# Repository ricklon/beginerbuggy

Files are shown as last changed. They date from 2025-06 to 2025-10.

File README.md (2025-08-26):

# Beginner Buggy
*A 1-pound combat robot platform for getting started in robot combat sports*





## 🤖 Project Overview

The **Beginner Combat Buggy** is an educational 1-pound antweight combat robot platform, designed to be fully 3D printed in plastic and compliant with antweight competition rules. This project provides a complete, buildable design that teaches fundamental robotics concepts while preparing participants for competition.

### Key Features
- **Competition Ready:** Meets standard 1lb plastic antweight combat robot specifications
- **Educational Focus:** Step-by-step learning experience for all skill levels
- **Modular Design:** Easy to modify, repair, and upgrade
- **Community Driven:** Open-source design with active builder support

### What You'll Learn
- Combat robot design principles
- Electronics integration and safety systems
- Mechanical assembly and fastening techniques
- Battery management and power systems
- Radio control and failsafe programming
- Competition preparation and strategy

## 📋 Specifications

| Specification | Value |
|---|---|
| **Weight Class** | 1 pound (454g) maximum |
| **Drive System** | Differential drive, tank steering |
| **Power System** | 2-4S LiPo battery with kill switch |
| **Control** | 2.4GHz radio with failsafe |
| **Motors** | Brushed gear motors |
| **ESC Options** | Repeat Robotics Budget Dual ESC<br>Weka 20A v2.2 Dual ESC |
| **Weapon Class** | Beginner-friendly (spinner/wedge/lifter) |
| **Arena Size** | Standard combat robotics arenas |

## 🚀 Getting Started

### Prerequisites
- Basic electronics knowledge (helpful but not required)
- Access to soldering equipment
- Precision scale (0.1g accuracy)
- Standard hobby tools

### Quick Start
1. **Read the Documentation** - Start with this README and the assembly guide
2. **Join the Community** - Connect with FUBAR Labs for build sessions
3. **Gather Materials** - Use the provided parts list and suppliers
4. **Attend Build Night** - Join a guided build session (recommended for beginners)
5. **Build and Test** - Follow the step-by-step assembly guide
6. **Compete** - Enter local antweight competitions

### Build Options
- **Guided Build Session** - Join FUBAR Labs build nights for hands-on instruction
- **Solo Build** - Follow the detailed assembly guide independently
- **Workshop Build** - Organize a group build at your local makerspace

## 📚 Documentation

### Core Documentation
- **[Assembly Guide](ASSEMBLY.md)** - Complete step-by-step build instructions
- **[Parts List](PARTS.md)** - Detailed component specifications and suppliers
- **[Competition Guide](COMPETITION.md)** - Rules, strategy, and event preparation

### Technical Resources
- **[Wiring Diagrams](docs/wiring/)** - Electrical schematics and connection guides
- **[CAD Files](cad/)** - 3D models and mechanical drawings
- **[Programming Guide](docs/programming/)** - ESC setup and radio configuration
- **[Troubleshooting](docs/troubleshooting/)** - Common issues and solutions

## 🔧 Hardware Components

### Electronics Package
- **Motor Controllers:** Repeat Robotics Budget Dual ESC or Weka 20A v2.2
- **Microcontroller:** Xiao development board
- **Power:** 2-4S LiPo battery with XT30 connectors
- **Safety:** Kill switch and weapon safety lock
- **Control:** 2.4GHz radio system with failsafe

### Mechanical Components
- **Chassis:** Lightweight aluminum or titanium frame
- **Drive:** Brushed gear motors with wheels
- **Fasteners:** High-strength bolts and grub screws
- **Protection:** Impact-resistant component mounting

### Tool Requirements
- Hex keys (2mm, 2.5mm, 4mm, 1.5mm)
- Torx keys (TBD)
- 7/16" wrench for lock nuts
- Soldering iron and supplies
- Precision scale (0.1g accuracy)
- Safety equipment (glasses, gloves)

## ⚡ Safety First

**🚨 IMPORTANT SAFETY NOTICE 🚨**

Combat robots involve weapons, high-energy systems, and LiPo batteries. **Safety is not optional.**

### Critical Safety Features
- **Kill Switch:** Emergency power disconnection
- **Weapon Safety Lock:** Physical weapon power removal
- **Block Testing:** Always elevate robot during testing
- **Battery Safety:** Proper LiPo handling and charging
- **Arena Requirements:** Contained testing environment

### Before You Build
- Read all safety documentation thoroughly
- Understand local regulations and venue requirements
- Have appropriate safety equipment available
- Know emergency procedures for electrical and fire hazards

**Never operate a combat robot without proper safety measures in place.**

## 🏆 Competition Information

### Competition Classes
- **Primary:** 1-pound plastic antweight class
- **Progression:** Path to 3lb, 12lb, and higher weight classes
- **Rules:** SPARC (Safety and Performance in Robotic Competition) guidelines

### Local Events
- **FUBAR Labs "Mechanical Mayhem"** - Regular antweight competitions
- **Regional Events** - Connect with broader combat robotics community
- **Tournament Formats** - Single elimination, round robin, skill challenges

### Getting Competition Ready
1. **Technical Inspection** - Pass safety and rules compliance check
2. **Weight Verification** - Confirm 1.000 lb maximum weight
3. **Safety Demonstration** - Prove all safety systems function
4. **Driver Preparation** - Practice maneuvering and weapon control

## 🛠️ Build Support

### FUBAR Labs Build Nights
- **Location:** FUBAR Labs makerspace
- **Schedule:** [Check calendar for dates]
- **What's Provided:** Tools, workspace, expert guidance
- **What to Bring:** Components, enthusiasm

### Community Support
- **Discord/Slack:** Real-time chat with builders and competitors
- **Build Photos:** Share progress and get feedback
- **Technical Help:** Troubleshooting assistance from experienced builders
- **Competition Prep:** Strategy and setup guidance

### Mentorship Program
- Pair new builders with experienced combat roboticists
- One-on-one guidance through first build and competition
- Ongoing support for design improvements and upgrades

## 📈 Project Roadmap

### Version 1.0 (Current)
- [x] Complete mechanical design
- [x] Electronics integration guide
- [x] Safety protocols established
- [x] Assembly documentation
- [ ] Competition validation
- [ ] Community feedback integration

### Version 2.0 (Planned)
- [ ] Advanced weapon options
- [ ] Weight optimization improvements
- [ ] CAD file refinements
- [ ] Video build tutorials
- [ ] Multi-language documentation

## 🤝 Contributing

We welcome contributions from builders, competitors, and educators!

### How to Contribute
- **Documentation:** Improve guides, add translations, create tutorials
- **Design:** Mechanical improvements, weight optimization, new features
- **Testing:** Build validation, competition feedback, safety verification
- **Community:** Organize build events, mentor new builders, share experiences

### Contribution Guidelines
1. Fork the repository
2. Create a feature branch
3. Make your changes with clear documentation
4. Test thoroughly (especially safety-related changes)
5. Submit a pull request with detailed description

### Code of Conduct
- **Safety First:** All contributions must prioritize builder and spectator safety
- **Inclusive Community:** Welcome builders of all skill levels and backgrounds
- **Open Collaboration:** Share knowledge freely and support others' learning
- **Responsible Innovation:** Consider the impact of changes on the community

## 📄 License and Legal

### Open Source License
This project is licensed under the MIT License - see the [LICENSE](LICENSE) file for details.

### Safety Disclaimer
**IMPORTANT:** Combat robotics involves inherent risks. Builders and operators assume full responsibility for safety. This project provides guidelines but cannot guarantee safety - always prioritize proper safety measures and follow local regulations.

### Competition Compliance
While designed to meet standard competition rules, builders are responsible for verifying compliance with specific event regulations. Rules may vary by competition and region.

## 🔗 Resources and Links

### Essential Reading
- [SPARC Safety Guidelines](https://sparc.tools/)
- [Combat Robotics Design Guidelines](https://www.robotcombat.com/)
- [LiPo Battery Safety](https://batteryuniversity.com/)

### Component Suppliers
- **Combat Electronics:** [Just Cuz Robotics](https://justcuzrobotics.com/), [Repeat Robotics](https://repeatrobotics.com/)
- **Mechanical Parts:** [McMaster-Carr](https://mcmaster.com/), Local hardware suppliers
- **Batteries:** Hobby electronics suppliers, specialized LiPo vendors

### Community
- **FUBAR Labs:** [https://fubarlabs.org/](https://fubarlabs.org/)
- **Facebook:** Local combat robotics groups
- **Discord:** Combat robotics community servers: GSCRL and Fubar Labs

## 📞 Contact and Support

### Project Maintainers
- **FUBAR Labs:** [contact information]
- **Build Support:** [discord]
- **Safety Questions:** [priority contact]

### Getting Help
1. **Check Documentation:** Most questions are answered in the guides
2. **Community Forums:** Discord/Slack for real-time help
3. **Build Sessions:** Attend FUBAR Labs events for hands-on assistance
4. **Direct Contact:** Reach out to maintainers for complex issues

### Reporting Issues
## 🛒 Buying Guide

Easily review and purchase the recommended components for your Beginner Combat Buggy build. This robot is designed to be 3D printed in plastic, making it lightweight and antweight compliant. Links and suggestions are provided for each category.

### Hardware
- **Chassis Frame:** 3D printed plastic (recommended: PETG, ABS, or PLA+), or lightweight aluminum/titanium (optional for custom builds)
- **Wheels:** Foam or cast wheels (Just Cuz Robotics, Repeat Robotics)
- **Fasteners:** High-strength bolts, grub screws (McMaster-Carr)
- **Mounts & Holders:** 3D printed or machined parts (see CAD files)

### Electronics
- **Motor Controllers (ESC):** Repeat Robotics Budget Dual ESC, Weka 20A v2.2 Dual ESC
- **Microcontroller:** Xiao development board (Seeed Studio, Amazon)
- **Radio System:** 2.4GHz transmitter/receiver (FlySky, Spektrum, FrSky)
- **Battery:** 2-4S LiPo battery, XT30 connectors (Hobby electronics suppliers)
- **Kill Switch:** XT30 inline switch (Just Cuz Robotics, Amazon)
- **Safety Lock:** Weapon power disconnect (custom or purchased)

### Motors
- **Drive Motors:** Brushed gear motors (Just Cuz Robotics, Repeat Robotics, Pololu)
- **Weapon Motors:** Spinner/lifter motors (optional, based on design)

### Tools
- **Hex Keys:** 2mm, 2.5mm, 4mm, 1.5mm (tool kits, Amazon)
- **Torx Keys:** As required by fasteners
- **Wrench:** 7/16" for lock nuts
- **Soldering Iron:** Basic hobby model
- **Precision Scale:** 0.1g accuracy (Amazon, eBay)
- **Safety Equipment:** Glasses, gloves

### Suppliers
- [Just Cuz Robotics](https://justcuzrobotics.com/)
- [Repeat Robotics](https://repeatrobotics.com/)
- [McMaster-Carr](https://mcmaster.com/)
- [Seeed Studio](https://www.seeedstudio.com/)
- Hobby electronics suppliers (local and online)

For detailed part numbers and specifications, see the [Parts List](PARTS.md).

---

## 🎯 Ready to Build?

**Welcome to combat robotics!** This project will take you from zero to competition-ready robot while teaching valuable engineering skills and connecting you with an amazing community.

**Next Steps:**
1. ⭐ Star this repository to stay updated
2. 📖 Read the [Assembly Guide](ASSEMBLY.md) thoroughly
3. 📋 Review the [Parts List](PARTS.md) and order components
4. 📅 Check for upcoming FUBAR Labs build sessions
5. 🔨 Start building your combat robot!

**Questions?** Don't hesitate to reach out - the combat robotics community is incredibly welcoming and always happy to help new builders succeed.

**Let's build some robots! 🤖⚔️**

**Welcome to combat robotics!** This project will take you from zero to competition-ready robot while teaching valuable engineering skills and connecting you with an amazing community.

**Next Steps:**
1. ⭐ Star this repository to stay updated
2. 📖 Read the [Assembly Guide](ASSEMBLY.md) thoroughly
3. 📋 Review the [Parts List](PARTS.md) and order components
4. 📅 Check for upcoming FUBAR Labs build sessions
5. 🔨 Start building your combat robot!

**Questions?** Don't hesitate to reach out - the combat robotics community is incredibly welcoming and always happy to help new builders succeed.

**Let's build some robots! 🤖⚔️**

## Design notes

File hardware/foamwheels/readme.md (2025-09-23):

FOAM Wheel Core Motor 4mm
FOAM Wheel Core Motor 3mm
FOAM Wheel Core DeadShaft
Locking Core

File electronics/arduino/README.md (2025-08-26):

# Arduino

Arduino code and documentation for electronics control.

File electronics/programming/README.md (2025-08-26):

# Programming Guide

This folder is for ESC setup and radio configuration documentation. Add your programming guides here.

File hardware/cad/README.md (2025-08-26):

# CAD Files

All 3D models and mechanical drawings for the project.

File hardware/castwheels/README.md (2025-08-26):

# Cast Wheels

CAD files and documentation for cast wheels.

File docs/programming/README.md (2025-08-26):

# Programming Guide

This folder is for ESC setup and radio configuration documentation for the Beginner Combat Buggy—a 1lb plastic antweight robot (commonly called a "plant").

All programming and electronics instructions in this project are designed for antweight compliance and 3D printed plastic construction.

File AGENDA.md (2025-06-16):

# Robot Build Night Meeting Agenda
## FUBAR Labs Beginner Combat Robot - 1lb Class

**Date:** [Meeting Date]  
**Time:** [Meeting Time]  
**Location:** FUBAR Labs  
**Project Repository:** https://github.com/fubarlabs/begginerbuggy  
**Competition Class:** 1-pound Combat Robot (Antweight)

---

## 1. Combat Robot Overview: What Are We Building? (15 minutes)

### Project Introduction
- **1-Pound Combat Robot Platform** - Entry-level combat robotics
- **Competition Class:** Antweight (1 lb maximum weight)
- **Purpose:** Getting started in robot combat sports
- **Design Philosophy:** Durable, reliable, and competitive platform for beginners

### Combat Robot Fundamentals
- **Weight Budget:** Every gram counts - strategic weight allocation
- **Durability:** Designed to withstand impacts and weapon strikes
- **Weapon Systems:** Offensive capabilities within class constraints
- **Mobility:** Speed and maneuverability for tactical advantage
- **Competition Ready:** Meeting technical inspection requirements

### Learning Path
- **Build Skills:** Mechanical assembly, electronics integration, testing
- **Competition Skills:** Strategy, driving, field repairs
- **Community:** FUBAR Labs "Mechanical Mayhem" and regional events
- **Progression:** 1lb → 3lb → 12lb → higher weight classes

---

## 2. System Architecture and Weight Distribution (20 minutes)

### Core Combat Systems
- **Drive System:** Tank drive for combat maneuverability (~25-30% weight)
- **Weapon System:** Spinner, wedge, or lifter (~20-40% weight)
- **Frame/Armor:** Structural protection (~20-30% weight)
- **Electronics:** ESCs, receiver, battery (~15-25% weight)
- **Reserves:** Weight margin for modifications (~5-10% weight)

### Design Integration
- **Component Protection:** Shielding electronics from weapon impacts
- **Modularity:** Quick component swapping between matches
- **Access Points:** Easy reach for connections and adjustments
- **Impact Paths:** Routing forces around critical components

### Weight Management Strategy
- **Precision Scale:** 0.1g accuracy for final verification
- **Component Substitution:** Trading performance vs. weight
- **Material Selection:** Strength-to-weight optimization

---

## 3. Battery System and Power Management (25 minutes)

### Battery Specifications and Equipment
- **Battery:** OVONIC 3S LiPo 450mAh - $20 for 2 batteries
- **Voltage:** 11.1V nominal (3S configuration)
- **Capacity:** 450mAh - optimized for 1lb weight budget
- **Discharge Rate:** High-discharge capable for combat loads
- **Charger:** ISDT PD60 Balance Charger - $15
- **Kill Switch:** Lynx Kill Switch - $12.50 (combat robotics standard)

### Microcontroller Options
- **Budget Option:** Xiao ESP32C3 - $10
- **Advanced Option:** Xiao ESP32S3 - $17
- **Features:** WiFi capability, compact form factor
- **Programming:** Arduino IDE compatible

### Control System
- **Controller:** Xbox Standard Controller - $60
- **Interface:** Wireless connection to microcontroller
- **Advantages:** Familiar ergonomics, reliable operation

### Charging System and Procedures
- **Balance Charger:** Individual cell monitoring and balancing
- **Charging Location:** Fire-safe area with LiPo bags
- **Charging Rate:** 1C maximum (capacity in mAh = charge current in mA)
- **Voltage Monitoring:** Pre-charge cell voltage verification
- **Storage Charge:** 3.8V per cell for long-term storage
- **Field Charging:** Portable setup for competition day

### Battery Connection and Mounting
- **Main Power Connector:** Secure, accessible connection point
- **Battery Mounting:** Shock-resistant, secure retention system
- **Quick Disconnect:** Easy battery removal for charging/replacement
- **Polarity Protection:** Reverse connection prevention
- **Impact Protection:** Battery containment during combat

### Power Distribution Design
- **Main Kill Switch:** Large, accessible emergency disconnect
- **Drive Circuit:** Independent power path with fusing
- **Weapon Circuit:** Separate power with removable safety link
- **Electronics Power:** Clean, regulated power for radio systems

---

## 4. Remote Control System (15 minutes)

### Radio System Requirements
- **2.4GHz Spread Spectrum:** Modern interference-resistant technology
- **Failsafe Programming:** Safe shutdown on signal loss
- **Channel Assignment:** Drive (2 channels), weapon (1 channel), aux functions
- **Range Testing:** Verify operation at competition distances

### Transmitter Setup
- **Control Mixing:** Tank steering or differential drive setup
- **Weapon Switch:** Momentary or toggle for weapon control
- **Emergency Features:** Kill switch and panic stop functions
- **Ergonomics:** Comfortable operation under stress

### Receiver Installation
- **Antenna Placement:** Clear path, away from metal components
- **Shock Mounting:** Protection from combat impacts
- **Binding Process:** Secure pairing with transmitter
- **Signal Validation:** Pre-match radio check procedures

---

## 5. Electronic Speed Controllers (ESCs) (25 minutes)

### ESC Selection Guidelines
- **Budget Build:** Repeat Robotics dual ESC - proven, cost-effective
- **Performance Build:** Weka 20A v2.2 - higher current, more features
- **Weight Considerations:** Both are compact dual-channel designs
- **Availability:** Check stock before build session
- **Programming:** Both support standard PWM input from receivers

### Recommended ESC Options
**Option 1: Repeat Robotics Dual ESC - $19.99**
- **Current Rating:** Dual channel brushed ESC
- **Voltage Range:** 2-4S LiPo compatible  
- **Form Factor:** Compact dual channel design
- **Advantages:** Budget-friendly, proven in combat, excellent value
- **Source:** itgresa.com (verified current pricing)

**Option 2: WEKA 20A v2.2 Dual ESC - $40+**
- **Current Rating:** 20A per channel
- **Weight:** Only 3 grams without wires
- **Features:** Overcurrent protection, undervoltage protection, mixing enabled by default
- **Advantages:** Premium features, ultra-lightweight, advanced protection circuits
- **Source:** justcuzrobotics.com, also available through itgresa.com

### ESC Programming and Setup
- **Throttle Calibration:** Full range PWM signal setup (1000-2000μs typical)
- **Acceleration Limiting:** Prevent wheel spin and loss of control
- **Brake Strength:** Aggressive stopping for quick direction changes
- **Failsafe Behavior:** Stop motors on signal loss
- **Thermal Protection:** Prevent damage from overheating
- **Motor Direction:** Software reversing vs. wire swapping

### Installation and Protection
- **Dual ESC Wiring:** Single board drives both motors
- **Power Input:** Direct battery connection with fusing
- **Signal Input:** Receiver channels for left/right drive
- **Heat Sinking:** Thermal management in confined space
- **Shock Mounting:** Vibration dampening and impact protection
- **Wire Routing:** Protect connections from weapon damage

### Testing Procedures
- **Bench Testing:** Verify programming before installation
- **Block Testing:** Robot on blocks so wheels spin freely - CRITICAL!
- **Signal Testing:** Full range operation verification
- **Current Testing:** Monitor power draw during operation
- **Thermal Testing:** Check for overheating during extended runs

---

## 6. Drive Motors and Mobility (20 minutes)

### Motor Selection
- **Motors:** Repeat Motors Mk 4mm - 2 for $20
- **Type:** Brushed gear motors (required for selected ESCs)
- **Voltage Rating:** Compatible with 3S LiPo system
- **Mounting:** 4mm shaft with grub screw attachment
- **Source:** itgresa.com

### Drive System Assembly
- **Motor Mounting:** M4 screws with thread locker
- **Grub Screw Installation:** Secure wheel attachment
- **Wheel Selection:** Balance grip, weight, and durability
- **Differential Drive:** Independent left/right control

### Motor Wiring (Critical!)
- **Right Motor:** Red wire to positive, black to remaining terminal
- **Left Motor:** Black wire to positive, red to remaining terminal
- **Wire Protection:** Route away from weapon and impact zones
- **Connector System:** Easy field replacement if damaged

### Drive Testing
- **Block Testing:** Always test with robot elevated off table
- **Direction Verification:** Ensure correct forward/reverse operation
- **Current Testing:** Monitor ESC current draw
- **Performance Testing:** Speed and torque verification

---

## 7. Weapon Systems (30 minutes)

### 1lb Weapon Options
- **Horizontal Spinners:** Disk or bar weapons for kinetic impact
- **Vertical Spinners:** Drum weapons for lifting opponents
- **Wedges:** Passive weapons for getting under opponents
- **Lifters:** Servo or pneumatic lifting mechanisms

### Weapon Safety Features (Built-In)
- **Removable Safety Link:** Physical disconnection of weapon power
- **Weapon Switch:** Dedicated arming control separate from drive
- **Spin-Down Timer:** Weapons must stop within 60 seconds
- **Impact Limiting:** Design for safe energy levels
- **Secure Mounting:** Weapon retention during combat

### Weapon Installation Procedures
- **Safety Link Removal:** Always remove before any weapon work
- **Mounting Hardware:** High-strength fasteners with thread locker
- **Balance Verification:** Static and dynamic balance testing
- **Containment Testing:** Verify weapon stays attached under load
- **Emergency Stop Testing:** Verify immediate shutdown capability

### Weapon Testing Protocol
- **Safety Area:** Contained testing environment only
- **Safety Equipment:** Eye protection, hearing protection mandatory
- **Progressive Testing:** Start slow, gradually increase speed
- **Vibration Monitoring:** Watch for dangerous resonances
- **Spin-Down Verification:** Confirm 60-second stop requirement

---

## 8. Assembly and Integration (20 minutes)

### Mechanical Assembly Sequence
- **Frame/Chassis:** Base structure assembly first
- **Drive Installation:** Motors and wheels with proper alignment
- **Electronics Mounting:** ESCs, receiver, battery compartment
- **Weapon Installation:** Last step, with safety link removed
- **Final Fastening:** Thread locker on all critical connections

### Electrical Integration
- **Power Distribution:** Main switch, fusing, safety links
- **Signal Routing:** Keep power and signal wires separated
- **Connector System:** Standardized connections for field repairs
- **Wire Management:** Secure routing away from moving parts

### Weight Verification
- **Progressive Weighing:** Check weight at each assembly stage
- **Component Substitution:** Swap parts if over weight limit
- **Final Verification:** Official scale check before competition

### Integration Testing
- **Systems Check:** All subsystems operational independently
- **Combined Testing:** Drive and weapon systems together
- **Block Testing:** Always elevate robot during powered testing
- **Competition Simulation:** Full operational test sequence

---

## 9. Test Arena and Competition Prep (15 minutes)

### Test Arena Setup
- **Safety Barriers:** Polycarbonate walls for weapon containment
- **Test Blocks:** Elevate robot for safe wheel testing
- **Emergency Stop:** Remote kill capability
- **Tool Access:** Field repair station setup
- **Weight Station:** Precision scale for verification

### Pre-Competition Testing
- **Technical Inspection Prep:** Practice competition tech check
- **Weight Verification:** Multiple scale confirmations
- **Safety Systems Check:** All safety features operational
- **Performance Testing:** Speed, weapon function, reliability
- **Documentation:** Wiring diagrams and spare parts inventory

### Competition Day Procedures
- **Battery Management:** Charging schedule and rotation
- **Safety Link Protocol:** Installation/removal procedures
- **Field Repair Kit:** Essential tools and spare parts
- **Match Preparation:** Pre-fight checks and setup

---

## 10. Materials and Tools Organization (25 minutes)

### Required Materials List

#### Mechanical Hardware
- **Shoulder Screws:** 5/16" diameter, various lengths, 1/4"-20 thread
- **Grub Screws:** M4 × 0.7mm, 4mm long (wheel attachment)
- **Motor Mount Screws:** M4 × 0.70mm, 20mm button head
- **Lock Nuts:** 1/4"-20 nylon insert type
- **Thread Locker:** Medium strength (blue) Loctite

#### Electronic Components
- **Combat ESCs:** 
  - **Option 1:** Repeat Robotics Budget Brushed Dual ESC (2-4S)
  - **Option 2:** Weka 20A v2.2 Dual ESC (Just Cuz Robotics)
- **Gear Motors:** Appropriate for 1lb class
- **LiPo Battery:** High discharge rate, appropriate capacity
- **Radio System:** 2.4GHz with failsafe
- **XT30 Connectors:** High-current battery connections
- **Safety Links:** Removable weapon safety disconnects

#### Tools and Equipment
- **Hex Keys:** 2mm, 2.5mm, 4mm (5/32"), 1.5mm
- **Precision Scale:** 0.1g accuracy for weight verification
- **Soldering Station:** For connector assembly
- **LiPo Charger:** Balance charger with safety features
- **Test Blocks:** Elevate robot for safe testing
- **Multimeter:** Electrical testing and troubleshooting

### Procurement Strategy
- **Combat Robotics Specialists:** itgresa.com (ESCs, motors, general combat parts)
- **Advanced ESCs:** justcuzrobotics.com (Weka and high-end controllers)
- **Electronics:** Amazon (batteries, chargers, controllers, general electronics)
- **Mechanical Hardware:** McMaster-Carr (fasteners, structural components)
- **Lead Times:** Combat robotics parts may have longer lead times
- **Budget Planning:** Total electronics package ~$130-180 depending on options

### Current Pricing (Updated June 2025)
**Budget Build Option:**
- **ESC:** Repeat Robotics Dual ESC - $19.99 (itgresa.com)
- **Motors:** Repeat Drive Brushed (pricing varies by configuration)
- **Microcontroller:** Xiao ESP32C3 - $10-17
- **Battery:** OVONIC 3S LiPo 450mAh - $20-25 for 4-pack
- **Charger:** ISDT PD60 Balance Charger - $19.99
- **Kill Switch:** Lynx Anti-Spark Switch - Available from multiple vendors
- **Controller:** Xbox Standard Controller - $60

**Performance Build Option:**
- **ESC:** WEKA 20A v2.2 Dual ESC - $40+ (justcuzrobotics.com)
- **Motors:** DartBox V2 or similar high-performance options
- **Other components:** Same as budget build

**Key Supplier Update:**
- **itgresa.com:** Confirmed source for Repeat Robotics ESC ($19.99), Lynx Switch, WEKA ESCs
- **justcuzrobotics.com:** WEKA ESCs, DartBox motors, advanced combat electronics
- **Amazon/Suppliers:** OVONIC 3S 450mAh 4-packs ($20-25), ISDT PD60 charger ($19.99)

---

## 11. Build Session Planning and Next Steps (10 minutes)

### Session Organization
- **Team Formation:** Pair experienced with newcomer builders
- **Work Stations:** Organized tool and component distribution
- **Progress Milestones:** Realistic completion goals
- **Safety Officer:** Designated oversight for all operations
- **Documentation:** Build notes and lessons learned

### Follow-Up Activities
- **Testing Sessions:** Progressive capability validation
- **Competition Preparation:** Practice driving and strategy
- **Field Repair Training:** Between-match maintenance skills
- **Design Iteration:** Improvements based on testing

### Competition Timeline
- **Technical Inspection:** Pre-competition safety and rules check
- **FUBAR Labs Events:** Local "Mechanical Mayhem" competitions
- **Regional Events:** Broader combat robotics community
- **Skill Development:** Advanced building and strategy workshops

---

## Questions and Discussion (10 minutes)

### Technical Q&A
- Component selection and sourcing questions
- Assembly sequence and integration challenges
- Testing procedures and safety protocols
- Competition rules and preparation

### Action Items
- Material procurement assignments
- Build session scheduling and venue setup
- Tool inventory and organization
- Competition registration and timeline

---

**Total Estimated Time:** 2 hours 45 minutes

**Critical Reminders:**
- Always use test blocks when powering up - never let robot run off table
- Remove safety links before any weapon work
- Charge batteries in fire-safe location with LiPo bags
- Progressive testing - start slow, verify each system

**Competition Context:** Preparing for FUBAR Labs "Mechanical Mayhem" antweight events

**Contact:** [Meeting organizer contact information]

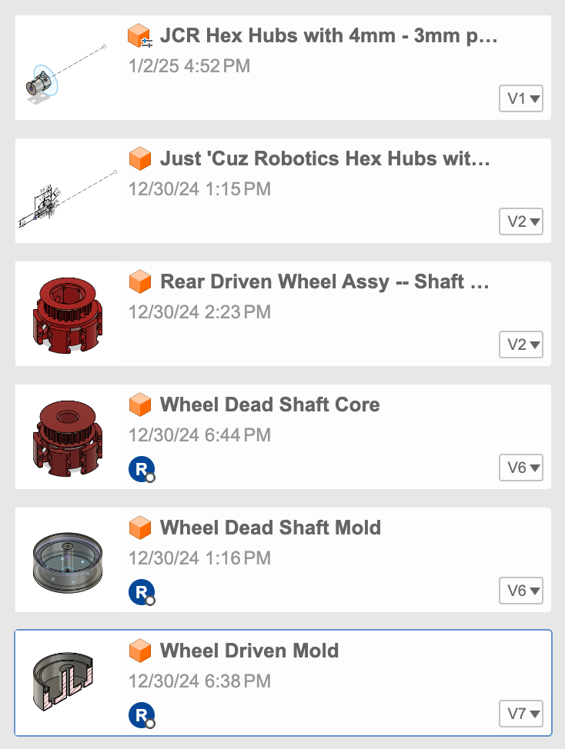
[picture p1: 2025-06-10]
hardware/castwheels/Screenshot_2025-01-03_at_2.17.39_PM.png

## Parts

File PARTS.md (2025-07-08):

# Combat Buggy Parts List and Bill of Materials

## Build Options Overview

| Component Category | Budget Build | Performance Build |
|---|---|---|
| **Total Cost** | $130-150 | $170-190 |
| **ESC** | Repeat Robotics Dual ($19.99) | Weka 20A v2.2 ($40+) |
| **Motors** | Repeat Motors Mk 4mm ($20) | Repeat Motors Mk 4mm ($20) |
| **Other Components** | Same | Same |

---

## Electronic Components

### Motor Speed Controllers (ESCs)

#### Option 1: Budget Build - Repeat Robotics Dual ESC
- **Part:** Repeat Robotics Budget Brushed Dual ESC (2-4S)
- **Price:** $19.99
- **Supplier:** itgresa.com
- **Features:** Dual channel brushed ESC, 2-4S LiPo compatible
- **Weight:** TBD
- **Quantity:** 1

#### Option 2: Performance Build - Weka 20A v2.2 Dual ESC
- **Part:** Weka 20A v2.2 Dual ESC
- **Price:** $40+
- **Supplier:** justcuzrobotics.com, also available through itgresa.com
- **Features:** 20A per channel, 3g weight without wires, overcurrent/undervoltage protection, mixing enabled
- **Weight:** 3g (without wires)
- **Quantity:** 1

### Drive Motors

- **Part:** Repeat Motors Mk 4mm
- **Price:** $20 for 2 motors
- **Supplier:** itgresa.com
- **Specifications:** Brushed gear motors, 4mm shaft with grub screw attachment, 3S LiPo compatible
- **Quantity:** 2

### Power System

#### Battery
- **Part:** OVONIC 3S LiPo 450mAh
- **Specifications:** 11.1V, 80C discharge rate, XT30 connector, 35g weight
- **Price:** $20-25 for 4-pack (recommended for competition rotation)
- **Supplier:** Amazon
- **Quantity:** 4-pack recommended (minimum 2)

#### Battery Charger
- **Part:** ISDT PD60 Balance Charger
- **Price:** $19.99
- **Specifications:** 60W, 6A max, 1-4S LiPo capable, USB-C input (5-20V)
- **Features:** Balance charging, upgradeable firmware, silent cooling
- **Supplier:** Amazon
- **Quantity:** 1

#### Kill Switch
- **Part:** Lynx Anti-Spark Kill Switch
- **Price:** Varies by vendor
- **Specifications:** High-current anti-spark design for combat robotics
- **Supplier:** itgresa.com, justcuzrobotics.com, various combat robotics vendors
- **Quantity:** 1

### Control System

#### Microcontroller - Budget Option
- **Part:** Xiao ESP32C3
- **Price:** $10
- **Features:** WiFi capability, compact form factor, Arduino IDE compatible
- **Quantity:** 1

#### Microcontroller - Advanced Option
- **Part:** Xiao ESP32S3
- **Price:** $17
- **Features:** Enhanced features over ESP32C3, WiFi capability
- **Quantity:** 1

#### Controller
- **Part:** Xbox Standard Controller
- **Price:** $60
- **Features:** Wireless connection to microcontroller, familiar ergonomics, reliable operation
- **Supplier:** Amazon, electronics retailers
- **Quantity:** 1

### Electrical Components

#### Power Connectors
- **Part:** XT30 Connectors (Male and Female)
- **Specifications:** High-current battery connections, male for battery side, female for robot side
- **Supplier:** Amazon, electronics suppliers
- **Quantity:** 2-4 pairs (spares recommended)

#### Wiring
- **Power Wires:** 16-18 AWG for main power and motor connections
- **Signal Wires:** 22-24 AWG for control signals
- **Heat Shrink Tubing:** Various sizes (2mm, 4mm, 6mm)
- **Solder:** 60/40 rosin core, 0.6-0.8mm diameter
- **Supplier:** Amazon, electronics suppliers

---

## Mechanical Components

### Fasteners

#### Torx Screws (NEW)
- **Part:** M3 × 12mm Torx Flat Head Thread-Forming Screws
- **Drive Size:** T8
- **Application:** Chassis mounting, plastic component attachment
- **Features:** 90° countersink, thread-forming for plastic
- **Supplier:** McMaster-Carr
- **Quantity:** TBD

- **Part:** M2 × 0.4mm × 6mm Torx Flat Head Screws
- **Drive Size:** T6
- **Material:** Zinc-plated steel
- **Application:** Motor mounting, electronics mounting
- **Supplier:** McMaster-Carr
- **Quantity:** TBD

#### Standard Fasteners
- **Part:** M4 × 0.7mm × 8mm Grub Screws (cup point)
- **Application:** Wheel attachment and securing points
- **Supplier:** McMaster-Carr
- **Quantity:** 8

- **Part:** M2 × 0.40mm × 5mm Flat Head Threading Screws
- **Application:** Various chassis connections
- **Supplier:** McMaster-Carr
- **Quantity:** TBD

- **Part:** M4 × 0.70mm × 20mm Button Head Screws
- **Application:** Motor mounting, structural connections
- **Supplier:** McMaster-Carr
- **Quantity:** 4

#### Shoulder Bolts
- **Part:** 5/16" × 7/8" or 1" Shoulder Screws (1/4"-20 thread)
- **Application:** Pivot points, structural connections
- **Supplier:** McMaster-Carr
- **Quantity:** 2

- **Part:** 1/4"-20 Nylon-Insert Lock Nuts
- **Application:** Securing shoulder screws
- **Supplier:** McMaster-Carr
- **Quantity:** 2

### Assembly Materials

#### Thread Locker
- **Part:** Loctite Medium Strength (Blue) Thread Locker
- **Application:** All critical threaded connections
- **Note:** Apply only during final assembly
- **Supplier:** Hardware stores, Amazon
- **Quantity:** 1 small bottle

#### Component Mounting
- **Part:** 3M Dual Lock Tape
- **Application:** Securing components without permanent attachment
- **Features:** Strong, removable mounting system
- **Supplier:** Amazon, industrial suppliers
- **Quantity:** 1 roll

### Mechanical Hardware

#### Chassis
- **Material:** Lightweight aluminum or titanium frame
- **Source:** Custom fabrication or 3D printing from provided CAD files
- **Files:** Available in `cad/` directory
- **Weight:** Optimized for 1lb weight budget

#### Wheels
- **Part:** Foam wheels with hex cores
- **Files:** CAD files available for 3D printing cores
- **Application:** Drive and support wheels
- **Quantity:** 4 (typically)

---

## Tools Required

### Hand Tools

#### Torx Keys (UPDATED)
- **T6 Torx L-Key:** 1-1/4" overall length (for M2 screws)
- **T8 Torx L-Key:** 1-3/4" overall length (for M3 screws)
- **Quality:** Professional grade recommended (Wera, Wiha, Bondhus)
- **Supplier:** McMaster-Carr, Amazon, tool suppliers

#### Hex Keys
- **Sizes:** 5/32" (4mm), 2.5mm, 2mm, 1.5mm
- **Additional:** Appropriate size for M2×5 screws
- **Quality:** Good quality L-keys or ball-end sets
- **Supplier:** Hardware stores, Amazon

#### Other Hand Tools
- **7/16" Wrench:** For lock nuts
- **Needle or Micro Flathead Screwdriver:** Fine adjustment work
- **Wire Strippers:** For 16-24 AWG wire
- **Precision Scale:** 0.1g accuracy for weight verification

### Electrical Tools

#### Soldering Equipment
- **Soldering Iron:** 25-40W with fine tip, temperature controlled preferred
- **Solder:** 60/40 rosin core, 0.6-0.8mm diameter
- **Flux:** Additional rosin flux for clean joints
- **Heat Gun or Hair Dryer:** For heat shrink tubing
- **Multimeter:** For continuity testing and voltage measurement

#### Testing Equipment
- **Test Blocks:** Elevate robot for safe wheel testing during assembly
- **LiPo Battery Tester:** Verify cell voltages
- **Work Light:** Good lighting for precise work (minimum 500 lux)

### Safety Equipment
- **Safety Glasses:** Required during soldering and assembly
- **Sand Bucket:** For smothering LiPo fires during motor/robot testing
- **Fire Extinguisher:** Electrical fire rated for general electrical safety
- **LiPo Charging Bag:** Fire-safe charging container
- **Well-Ventilated Area:** Or fume extractor for soldering

---

## Suppliers and Procurement

### Primary Suppliers

- **itgresa.com:** Repeat Robotics ESC ($19.99), Repeat Motors ($20), Lynx Kill Switch, Weka ESCs
- **justcuzrobotics.com:** Weka 20A v2.2 ESC ($40+), advanced combat electronics
- **Amazon:** OVONIC batteries ($20-25), ISDT charger ($19.99), Xbox controllers ($60), XT30 connectors
- **McMaster-Carr:** All fasteners, precision hardware, thread locker, professional tools

### Lead Times
- **Combat Robotics Parts:** May have longer lead times, order early
- **Standard Electronics:** Usually 1-3 days from Amazon
- **Precision Fasteners:** McMaster-Carr typically next-day delivery

### Budget Planning
- **Budget Build:** $130-150 | **Performance Build:** $170-190 | **Tools:** $50-100 (one-time)

---

## Weight Budget Analysis

| Component Category | Typical Weight | Notes |
|---|---|---|
| **Electronics** | 120-150g | ESC, motors, battery, microcontroller |
| **Chassis** | 150-200g | Aluminum/titanium frame |
| **Fasteners** | 20-30g | All screws, bolts, hardware |
| **Wheels** | 40-60g | Foam wheels with cores |
| **Miscellaneous** | 30-50g | Wiring, mounting materials |
| **Total Target** | ~450g | 4g margin for 454g limit |

### Weight Optimization Tips
- **Minimize wire length** - every inch adds weight
- **Use appropriate fastener sizes** - don't oversize
- **Choose lightweight chassis materials**
- **Remove excess material** where structurally safe

---

## Quality and Specification Notes

### Critical Specifications
- **XT30 Polarity:** Male connector on battery (larger terminal = positive)
- **Thread Pitch:** M2 × 0.4mm fine pitch for precision mounting
- **Battery Capacity:** 450mAh optimized for 1lb weight budget
- **ESC Current Rating:** Must handle motor stall current safely

### Quality Recommendations
- **Torx Tools:** Quality bits prevent stripping
- **Battery Safety:** Use balance charger, never leave charging unattended. Keep sand bucket nearby during testing - LiPo fires must be smothered, not extinguished with water
- **Fastener Quality:** Use proper grade fasteners from reputable suppliers
- **Competition Spares:** Carry extra XT30 connectors and fasteners

---

## Revision History

| Version | Date | Changes |
|---|---|---|
| 1.0 | 2025-07-08 | Initial consolidated parts list creation |
| | | Added specific Torx fastener specifications |
| | | Consolidated information from ASSEMBLY.md and AGENDA.md |
| | | Added detailed supplier information and pricing |

---

**Note:** This parts list consolidates information previously scattered across multiple documents. All builders should verify current pricing and availability before ordering, as costs and suppliers may change.

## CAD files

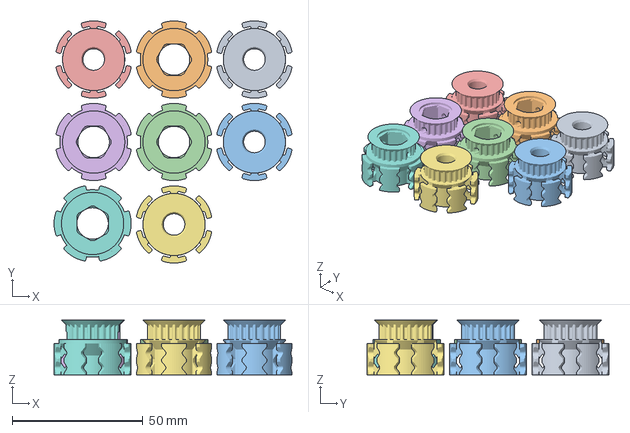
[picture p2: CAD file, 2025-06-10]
hardware/castwheels/CastHubsSetCores.3mf
90.9 x 92.5 x 21.0 mm
Hub Front x 4
Hub Rear x 4

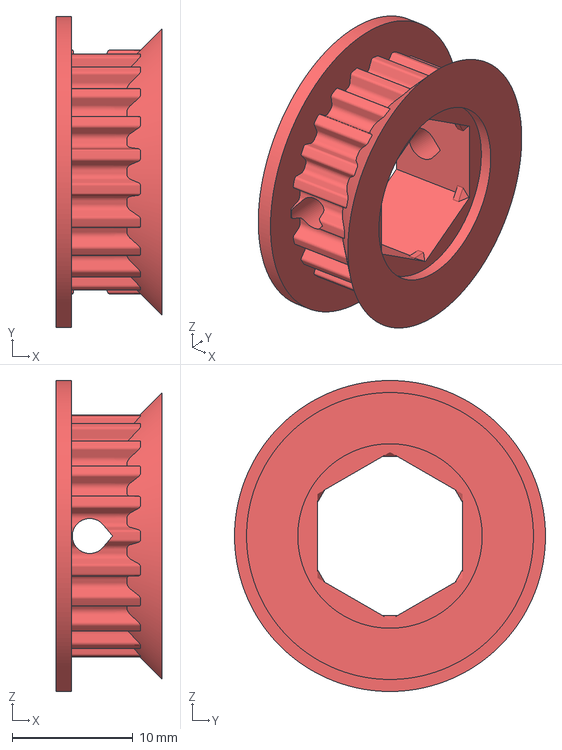
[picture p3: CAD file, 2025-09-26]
hardware/foamwheels/HubInnerPulley.3mf
8.81 x 25.8 x 25.8 mm

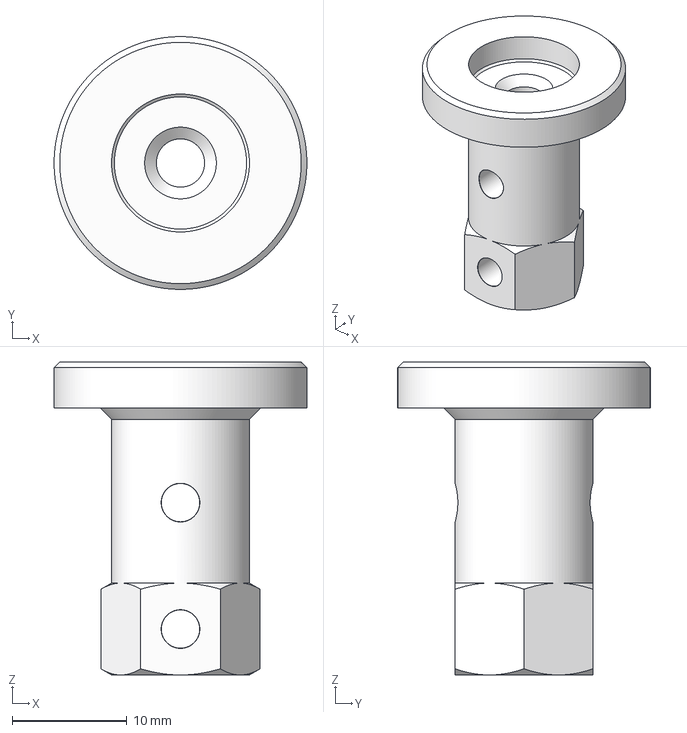
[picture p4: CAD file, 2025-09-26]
hardware/foamwheels/HexCore_4mm.3mf
22.0 x 22.0 x 27.2 mm

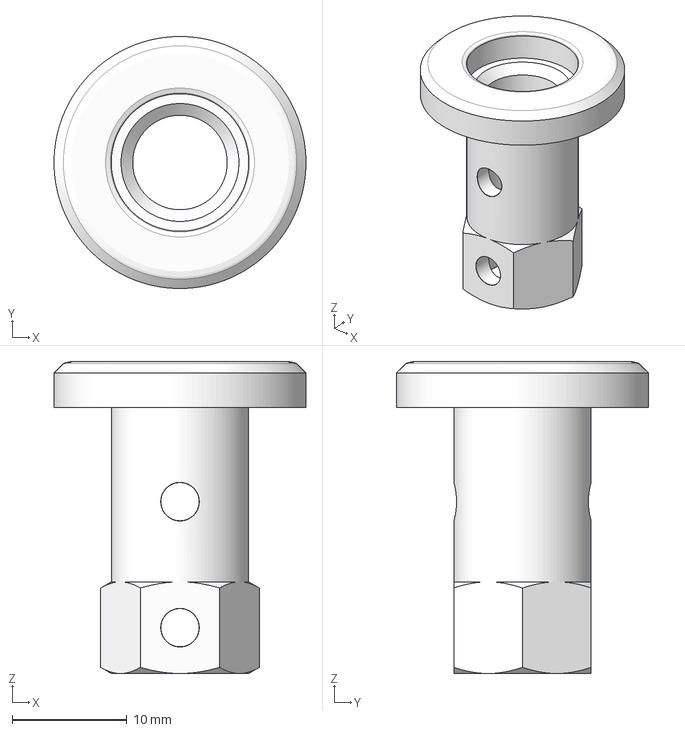
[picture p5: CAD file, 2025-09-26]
hardware/foamwheels/hexhub_Deadshaft.3mf
22.0 x 22.0 x 27.2 mm

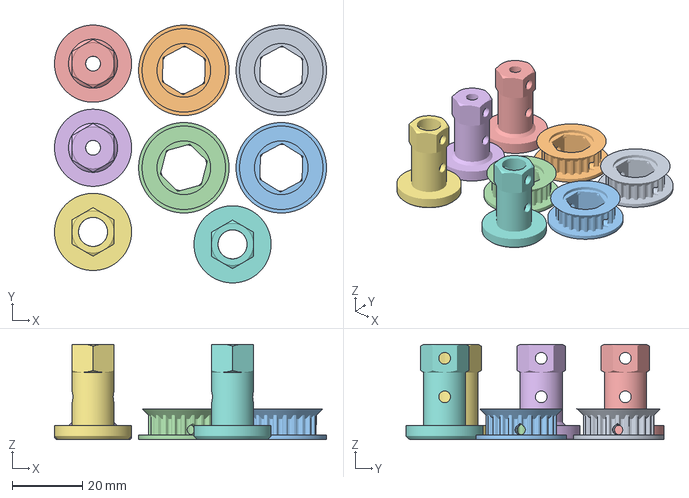
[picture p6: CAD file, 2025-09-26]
hardware/foamwheels/beginner_buggy_wheel_cores_and_pulley.3mf
77.6 x 73.5 x 27.2 mm
Hub Rear x 4

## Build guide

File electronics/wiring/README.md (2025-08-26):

# Wiring

Wiring diagrams and electrical schematics.

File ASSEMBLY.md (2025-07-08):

# Beginner Combat Buggy Assembly Guide
## Step-by-Step Instructions

---

## Pre-Assembly Preparation

### Procurement Information
**Specialized Combat Robotics Parts:**
- **itgresa.com:** Repeat Robotics ESC ($15), Repeat Motors Mk 4mm ($20), combat-specific parts
- **justcuzrobotics.com:** Weka 20A v2.2 ESC ($40), advanced combat electronics
- **Amazon:** OVONIC batteries ($20), ISDT charger ($15), Xbox controller ($60)
- **McMaster-Carr:** Fasteners, mechanical hardware

**Budget Planning:** Total cost approximately $130-180 depending on component choices

### Parts Inventory Check
**Verify you have all components before starting:**

**Shoulder Bolts:**
- [ ] 2× 5/16" × 3/4" shoulder screws (1/4"-20 thread)
- [ ] 1/4"-20 nylon-insert lock nuts

**Fasteners:**
- [ ] 8× M4 × 0.7mm × 8mm grub screws (cup point) - *Updated quantity and length*
- [ ] M2 × 6mm screws for motor mounting
- [ ] M2 × 0.40mm × 5mm flat head threading screws
- [ ] 4× M4 × 0.70mm × 20mm button head screws

**Electronics:**
- [ ] Repeat Drive Brushed motors or compatible brushed gear motors
- [ ] Combat ESC: Repeat Robotics Dual ($19.99) or WEKA 20A v2.2 ($40+)
- [ ] Xiao ESP32C3 ($10) or ESP32S3 ($17) microcontroller
- [ ] OVONIC 3S LiPo 450mAh batteries - 4-pack ($20-25)
- [ ] ISDT PD60 Balance Charger - $19.99
- [ ] Lynx Anti-Spark Switch (pricing varies by vendor)
- [ ] Xbox Standard Controller - $60
- [ ] XT30 connectors and wiring
- [ ] 3M Dual Lock tape

### Tool Setup
**Organize your workspace with:**
- [ ] Hex keys: 5/32" (4mm), 2.5mm, 2mm, 1.5mm, plus appropriate size for M2×5 screws
- [ ] 7/16" wrench
- [ ] Needle or micro flathead screwdriver
- [ ] Soldering iron and supplies
- [ ] Good lighting/work lamp
- [ ] Loctite thread locker (KEEP SEALED until final assembly)

---

## Stage 1: Wheel Preparation

### Step 1: Install Wheel Cores
1. **Insert cores into wheels**
   - Press cores firmly into wheel hubs
   - Ensure cores are fully seated and flush
   - Check that core orientation matches wheel design

2. **Pre-thread wheel connections**
   - Use M4 threading screw to cut clean threads
   - Thread screw in completely, then back out
   - **Purpose:** Ensures grub screws will thread smoothly
   - Clean out any plastic debris

### Step 2: Prepare Grub Screw Connections
1. **Test fit grub screws**
   - Thread M4 × 8mm grub screws into connections (8 total available)
   - Should thread smoothly after pre-threading
   - **Note:** 8 grub screws provided for wheel attachment and other securing points
   - Back out screws but keep them organized by intended location

**✓ Stage 1 Check:** All wheels have cores installed, connections are pre-threaded

---

## Stage 2: Drive Motor Installation

### Step 3: Mount Drive Motors to Chassis
1. **Position drive motors**
   - Align motors with chassis mounting holes
   - Ensure motor shafts are parallel and level
   - Check clearance for wheel installation

2. **Install motor mounting screws**
   - Use M2 × 5mm screws for motor mounting
   - **Do NOT apply Loctite yet** - this is temporary mounting
   - Tighten to snug fit, allow for adjustment

### Step 4: Attach Wheels to Motors
1. **Install drive wheels (motor-powered wheels)**
   - Slide wheel onto motor shaft
   - Locate flat section on motor shaft
   - Position first grub screw against flat section
   - **Tighten first grub screw firmly**

2. **Install second grub screw**
   - Position 180° opposite from first grub screw
   - This prevents wheel from spinning on shaft
   - **Tighten second grub screw**

3. **Install dead shaft wheels (non-powered)**
   - Mount remaining wheels to chassis
   - Use grub screws as wheel locks/axle retention
   - Ensure wheels spin freely

**✓ Stage 2 Check:** 
- All wheels installed and secure
- Drive wheels don't slip on motor shafts
- Dead shaft wheels spin freely
- Motors are securely mounted

---

## Stage 3: Electronics Preparation

### Step 5: Motor Controller Wiring
**Choose your ESC option before beginning:**

#### Option A: Repeat Robotics Budget Dual ESC ($19.99)
**Required Materials:**
- 16-18 AWG wire for power connections
- 22-24 AWG wire for signal connections  
- XT30 connector (female for robot side)
- Heat shrink tubing (2mm, 4mm, 6mm sizes)
- Rosin flux and 60/40 solder

**Power Input Wiring:**
1. **Prepare XT30 connector (Robot Side - Female):**
   - Cut red and black wire to 4-6 inches length
   - Strip 4-5mm of insulation from wire ends
   - Pre-tin both wires with thin solder coating
   - **CRITICAL:** Larger socket = positive (red), smaller socket = negative (black)

2. **Solder XT30 connections:**
   - Slide heat shrink over wires before soldering
   - Heat XT30 terminal cups with soldering iron
   - Insert pre-tinned wire and fill cup completely with solder
   - Hold steady for 3-5 seconds until solder cools
   - Slide heat shrink over connections and shrink with heat gun
   - **Test with multimeter for continuity and correct polarity**

3. **Connect to ESC power input:**
   - Identify V+ and GND pads on ESC (usually clearly marked)
   - Pre-tin ESC pads with thin layer of solder
   - Solder red wire to V+ pad, black wire to GND pad
   - **Keep wires short** to minimize weight and resistance

**Motor Output Wiring:**
1. **Prepare motor wires:**
   - Use 16-18 AWG wire, approximately 6-8 inches per motor
   - Strip and pre-tin motor terminal tabs
   - Strip and pre-tin wire ends (3-4mm length)

2. **Solder motor connections:**
   - **Right Motor (Motor A):** Red wire to positive terminal, black to negative
   - **Left Motor (Motor B):** Black wire to positive terminal, red to negative
   - **Note:** Opposite polarity on left motor for proper drive direction
   - Wrap wire around terminal clockwise before soldering
   - Apply heat and solder to create strong mechanical and electrical joint
   - Cover all connections with heat shrink tubing

3. **Connect to ESC motor outputs:**
   - ESC should have clearly marked Motor A and Motor B outputs
   - Solder motor wires to corresponding ESC output pads
   - **Double-check polarity** - incorrect wiring can damage ESC

**Signal Connections:**
1. **ESP32 to ESC signal wiring:**
   - Use 22-24 AWG wire for signal connections
   - Connect ESP32 Pin D0 to ESC Channel A signal input
   - Connect ESP32 Pin D1 to ESC Channel B signal input  
   - Connect ESP32 GND to ESC signal ground
   - **Keep signal wires away from power wires** to prevent interference

#### Option B: Weka 20A v2.2 Dual ESC ($40+)
**Key Differences:**
- Higher current capacity (20A per channel vs ~10A for Repeat ESC)
- Built-in mixing for tank steering
- Only 3g weight without wires
- May include servo-style signal connectors

**Follow same basic wiring procedure as Option A, with these modifications:**
- Use same XT30 power input wiring
- Motor outputs may have different pad layout - consult ESC documentation
- Signal inputs may use standard servo connectors instead of direct solder
- Built-in mixing may simplify programming requirements

**ESC Programming Notes:**
- Both ESCs require throttle range calibration with ESP32
- Set failsafe behavior to stop motors on signal loss
- Configure acceleration limiting to prevent wheel spin
- Test all functions before final assembly

### Enhanced XT30 Connector Safety Procedures

**CRITICAL SAFETY WARNING:** Incorrect XT30 installation can cause:
- Reverse polarity damage to ESC and battery
- Short circuits leading to fire
- Permanent component damage

**Visual Identification Guide:**
```
Male XT30 (Battery Side):
┌─────────────────┐
│  Large   Small  │  ← Terminals
│   (+)     (-)   │  ← Polarity
└─────────────────┘

Female XT30 (Robot Side):
┌─────────────────┐
│ Socket  Socket  │
│ Large   Small   │  ← Sockets
│  (+)     (-)    │  ← Polarity  
└─────────────────┘
```

**Step-by-Step XT30 Installation:**
1. **Verify connector type**: Male (battery), Female (robot)
2. **Check terminal size**: Large = positive, Small = negative
3. **Pre-tin all surfaces** with rosin flux and solder
4. **Heat terminal cup** with 40W iron until solder melts
5. **Insert wire and add solder** - fill cup completely
6. **Hold steady 5 seconds** - do not move until cooled
7. **Install heat shrink** over entire connection
8. **Test with multimeter**: 
   - Continuity through connector
   - No shorts between terminals
   - Correct polarity marking

### Pre-Power Testing Checklist

**Before connecting battery for first time:**
- [ ] XT30 connectors properly soldered and insulated
- [ ] Motor wires connected with correct polarity
- [ ] Signal wires properly routed and connected
- [ ] No loose solder strands or wire fragments
- [ ] All connections covered with heat shrink
- [ ] Kill switch in OFF position
- [ ] Multimeter continuity tests completed

**Initial Power-Up Safety:**
- [ ] Robot elevated on blocks (wheels cannot touch ground)
- [ ] Fire extinguisher nearby for LiPo safety
- [ ] Clear workspace around robot
- [ ] Battery at proper voltage (11.1V ± 0.5V for 3S)
- [ ] All personnel wearing safety glasses

### Wire Management Best Practices

**Power Wire Routing:**
- Keep power wires as short as practical
- Secure with cable ties every 2-3 inches
- Route away from wheels and moving parts
- Avoid sharp chassis edges that could cut insulation

**Signal Wire Protection:**
- Run signal wires separate from power wires (minimum 10mm separation)
- Use twisted pair wire for differential signals if possible
- Secure signal wires to prevent stress on solder joints
- Consider shielded cable in high-noise environments

**Weight Optimization:**
- Use minimum wire gauge that meets current requirements
- Trim excess wire length after testing
- Remove unnecessary wire jacket where safe
- Bundle related wires with thin cable ties

### Troubleshooting Common Soldering Issues

**Cold Solder Joints:**
- **Symptoms:** Dull, grainy appearance; poor electrical connection
- **Causes:** Insufficient heat, old solder, dirty surfaces
- **Solution:** Clean surfaces, use flux, apply adequate heat

**Solder Bridges:**
- **Symptoms:** Unwanted connections between adjacent pads
- **Causes:** Too much solder, insufficient flux, shaky hands
- **Solution:** Use solder wick to remove excess, clean with isopropyl alcohol

**Overheated Components:**
- **Symptoms:** Discolored PCB, lifted pads, component damage
- **Causes:** Too much heat, too long contact time
- **Prevention:** Use temperature-controlled iron, work quickly, heat sink if needed

**Poor Wire Connections:**
- **Symptoms:** High resistance, intermittent connections
- **Causes:** Insufficient pre-tinning, cold joints, stress on connection
- **Solution:** Re-work connection with proper technique

### Safety Equipment and Procedures

**Required Safety Equipment:**
- Safety glasses (always worn during soldering)
- Well-ventilated area or fume extractor
- Fire extinguisher rated for electrical fires
- First aid kit with burn treatment supplies
- Proper lighting (minimum 500 lux at work surface)

**Emergency Procedures:**
- **Electrical burn:** Cool with water immediately, seek medical attention
- **Solder fume exposure:** Move to fresh air, seek medical attention if symptoms persist
- **Component fire:** Disconnect power, use appropriate fire extinguisher
- **Battery fire:** Evacuate area, call fire department, do not use water

### Maintenance and Inspection

**Post-Assembly Inspection:**
- Visual inspection of all solder joints
- Mechanical stress test of connections
- Electrical continuity verification
- Insulation resistance testing

**Periodic Maintenance:**
- Check for loose connections after each use
- Inspect wire insulation for damage
- Clean corrosion from connectors
- Re-tighten mechanical fasteners as needed

**Competition Day Checks:**
- Battery voltage verification
- Connector cleanliness and tightness
- Wire routing security
- Kill switch operation
- Emergency stop functionality

### Step 6: ESP32 Microcontroller Setup
1. **Install headers on Xiao ESP32C3 or ESP32S3**
   - Solder headers as needed for connections
   - Ensure pins are straight and properly aligned
   - Test fit with intended connections

2. **Programming preparation:**
   - Set up Arduino IDE with ESP32 board support
   - Verify board can be programmed before final installation

### Control System Setup
1. **Xbox Controller Configuration:**
   - Pair Xbox Standard Controller with ESP32 microcontroller
   - Configure wireless connection and button mapping
   - Test controller response and range
   - Set up emergency stop functions

2. **Programming the control system:**
   - Upload control software to ESP32
   - Configure drive mixing (tank steering or arcade style)
   - Set up weapon control (if applicable)
   - Test failsafe behavior

**✓ Stage 3 Check:**
- Motor wiring completed with correct polarity
- Headers installed and soldered cleanly
- Connectors properly modified and tested

---

## Stage 4: Power System Integration

### Step 8: Lynx Kill Switch Installation
1. **Choose switch placement**
   - Position Lynx kill switch for easy access during operation
   - Consider high-side switching for safety
   - Plan wire routing to avoid mechanical interference

2. **Solder XT30 connectors**
   - **Battery side:** Connect to OVONIC 3S LiPo 450mAh battery
   - **Robot side:** Female XT30 connector to robot power system
   - Use proper polarity (red = positive, black = negative)
   - **Test continuity** before final installation

### Battery System Setup
1. **OVONIC 3S LiPo 450mAh Battery (4-pack recommended):**
   - **Specifications:** 11.1V, 80C discharge rate, XT30 connector
   - **Weight:** 35g per battery, perfect for 1lb weight budget
   - **Pricing:** $20-25 for 4-pack (better value than 2-pack)
   - Verify cell voltages before first use (should be ~3.7-3.85V per cell)
   - Use ISDT PD60 charger for all charging operations
   - Always charge in fire-safe location with LiPo bag
   - Monitor charging - never leave unattended

2. **ISDT PD60 Charger ($19.99):**
   - **Specifications:** 60W, 6A max, 1-4S LiPo capable
   - **Input:** USB-C (5-20V), works with power banks or wall adapters
   - **Features:** Balance charging, upgradeable firmware, silent cooling
   - Balance charge at 1A rate (450mA) for 450mAh batteries
   - Storage charge to 3.8V per cell for long-term storage
   - Check for damage before each use

### Step 9: Power System Connections
1. **Connect battery to kill switch**
   - Verify polarity before connection
   - Ensure secure, tight connection
   - Test switch operation (ON/OFF)

2. **Connect kill switch to motor controller**
   - Route power through kill switch
   - Verify voltage at motor controller with switch ON
   - Confirm zero voltage with switch OFF

3. **Connect motor controller to motors**
   - Use prepared motor wiring from Stage 3
   - **Double-check polarity** before powering up
   - Secure all connections

**✓ Stage 4 Check:**
- Kill switch operates correctly
- All power connections secure and correct polarity
- System ready for initial testing

---

## Stage 5: System Integration and Testing

### Step 10: Component Mounting
1. **Mount components with 3M Dual Lock**
   - Clean mounting surfaces with alcohol
   - Apply Dual Lock to chassis and components
   - Position components for easy access and protection
   - **Press firmly** to ensure good adhesion

2. **Secure wire routing**
   - Keep wires away from wheels and moving parts
   - Use additional Dual Lock or cable ties
   - Ensure no pinch points or stress on connections

### Step 11: Initial System Testing
**⚠️ SAFETY FIRST - ALWAYS TEST ON BLOCKS**

1. **Pre-power checklist:**
   - [ ] Kill switch in OFF position
   - [ ] All connections secure
   - [ ] Robot elevated on blocks (wheels can't touch ground)
   - [ ] Clear workspace around robot

2. **Power-up sequence:**
   - Connect battery
   - Turn kill switch to ON
   - **Immediately verify no unexpected movement**
   - Check for proper voltage at all components

3. **Motor function test:**
   - Test each motor individually
   - Verify correct rotation direction
   - Check that wheels don't slip on shafts
   - **Turn OFF immediately after testing**

**✓ Stage 5 Check:**
- All components securely mounted
- Initial testing successful with no issues
- Robot ready for final assembly

---

## Stage 6: Final Assembly and Locking

### Step 12: Final Testing and Adjustment
1. **Complete operational test:**
   - **Robot still on blocks** - wheels off ground
   - Test all motor functions
   - Verify kill switch emergency stop
   - Check for any loose connections or components

2. **Make final adjustments:**
   - Tighten any loose mechanical connections
   - Adjust component positions if needed
   - Verify all systems operate as expected

### Step 13: Apply Thread Locker (FINAL STEP)
**⚠️ PERMANENT - Only do this when completely satisfied with assembly**

1. **Disassemble critical connections:**
   - Remove motor mounting screws one at a time
   - Apply small drop of Loctite to threads
   - Reinstall and tighten to proper torque

2. **Apply to all threaded connections:**
   - Motor mount screws
   - Grub screws (if accessible)
   - Any chassis fasteners
   - **Do NOT over-apply** - small amount is sufficient

3. **Final cure time:**
   - Allow 24 hours for full cure
   - Avoid disassembly during cure period

**✓ Final Check:**
- All threaded connections have thread locker
- Robot tested and operational
- Assembly documentation complete

---

## Final Safety Verification

### Pre-Operation Checklist
Before each use, verify:
- [ ] Battery fully charged and properly connected
- [ ] Kill switch operates correctly
- [ ] All mechanical connections tight
- [ ] No loose wires or components
- [ ] Wheels secure on shafts
- [ ] Clear operating area

### Emergency Procedures
- **Immediate shutdown:** Kill switch to OFF position
- **Runaway robot:** Kill switch first, then disconnect battery
- **Electrical issues:** Disconnect battery, do not attempt field repairs
- **Mechanical damage:** Stop operation, assess damage before continuing

---

## Troubleshooting Guide

### Motor Not Running
1. Check kill switch position
2. Verify battery voltage
3. Check motor controller connections
4. Test motor resistance (should be low, not infinite)

### Motor Running Wrong Direction
1. Swap motor wires at controller
2. Check control signal polarity
3. Verify controller programming

### Wheel Slipping on Motor Shaft
1. Check grub screw tightness
2. Verify flat section alignment
3. Clean motor shaft if oily

### Intermittent Operation
1. Check all wire connections
2. Verify battery connections
3. Test kill switch continuity
4. Check for loose Dual Lock mounting

---

## Maintenance Schedule

### After Each Use
- Check for loose screws or components
- Verify battery connections
- Clean debris from wheels and chassis

### Weekly (Heavy Use)
- Test kill switch operation
- Check motor mounting tightness
- Verify all electrical connections

### Monthly
- Deep clean chassis and components
- Check thread locker integrity
- Lubricate moving parts if needed

---

**Assembly Complete!**  
**Your combat robot is ready for testing and competition.**

**Remember:** Always operate on blocks for initial testing, never let the robot run off a table or work surface.

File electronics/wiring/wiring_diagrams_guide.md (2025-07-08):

# Combat Buggy Wiring Diagrams and Soldering Guide

## Table of Contents
1. [System Overview](#system-overview)
2. [Component Connections](#component-connections)
3. [Power Distribution](#power-distribution)
4. [ESC Wiring Options](#esc-wiring-options)
5. [Soldering Procedures](#soldering-procedures)
6. [Wire Management](#wire-management)
7. [Testing and Verification](#testing-and-verification)
8. [Troubleshooting](#troubleshooting)

---

## System Overview

### Main Electrical Components
- **Power Source:** OVONIC 3S LiPo 450mAh battery (11.1V nominal)
- **Main Switch:** Lynx Anti-Spark Kill Switch
- **Motor Controller:** Repeat Robotics Dual ESC or Weka 20A v2.2
- **Microcontroller:** Xiao ESP32C3/S3
- **Motors:** Repeat Drive Brushed gear motors (2x)
- **Connectors:** XT30 for main power

### Electrical System Architecture
```
[Battery] → [XT30] → [Kill Switch] → [ESC] → [Motors]
                         ↓
                   [Microcontroller] → [Receiver/Controller]
```

---

## Component Connections

### Main Power Circuit

#### Battery to Kill Switch
```
Battery (+) → Red Wire → Kill Switch Input (+)
Battery (-) → Black Wire → Common Ground
```

#### Kill Switch to ESC
```
Kill Switch Output (+) → Red Wire → ESC V+ Input
Common Ground → Black Wire → ESC GND Input
```

#### ESC to Motors
```
ESC Motor A (+) → Red Wire → Motor 1 (+)
ESC Motor A (-) → Black Wire → Motor 1 (-)
ESC Motor B (+) → Red Wire → Motor 2 (+)
ESC Motor B (-) → Black Wire → Motor 2 (-)
```

### Control Circuit

#### ESP32 to ESC Signal Connections
```
ESP32 Pin D0 → ESC Channel A Signal (Left Motor)
ESP32 Pin D1 → ESC Channel B Signal (Right Motor)
ESP32 GND → ESC Signal Ground
ESP32 5V → ESC 5V Output (if available)
```

---

## Power Distribution

### Main Power Path Diagram
```
[3S LiPo Battery]
    |
    | XT30 Connector
    |
[Lynx Kill Switch]
    |
    | High Current Path (Drive Motors)
    |
[Motor Controller/ESC]
    |
    ├─ Motor A (Left Drive)
    └─ Motor B (Right Drive)
```

### Auxiliary Power
```
[ESC 5V Output] → [ESP32 5V Input]
                → [Receiver Power]
```

### Power Specifications
- **Main Circuit:** 11.1V nominal (12.6V fully charged)
- **Maximum Current:** 20A per motor channel
- **Control Circuit:** 5V regulated from ESC
- **Signal Levels:** 3.3V PWM signals from ESP32

---

## ESC Wiring Options

### Option 1: Repeat Robotics Budget Dual ESC

#### Connector Pinout
```
Power Input:
- Red Wire: Battery Positive (V+)
- Black Wire: Battery Negative (GND)

Motor Outputs:
- Motor A: Red/Black wire pair
- Motor B: Red/Black wire pair

Signal Input:
- Channel A: White/Orange wire (PWM signal)
- Channel B: White/Orange wire (PWM signal)
- Ground: Brown/Black wire (Signal ground)
```

#### Connection Sequence
1. **Power Connections First:**
   - Solder XT30 connector to main power input
   - Connect kill switch in series with positive lead
   - Verify polarity before applying power

2. **Motor Connections:**
   - Use 16-18 AWG wire for motor connections
   - Solder directly to motor terminals
   - Apply heat shrink tubing over connections

3. **Signal Connections:**
   - Connect to ESP32 PWM outputs
   - Use 22-24 AWG wire for signal connections
   - Keep signal wires away from power wires

### Option 2: Weka 20A v2.2 Dual ESC

#### Features and Connections
- **Weight:** Only 3g without wires
- **Protection:** Overcurrent and undervoltage protection
- **Mixing:** Enabled by default for tank steering

#### Wiring Differences
```
Power Input: Same as Repeat ESC
Motor Outputs: Higher current capacity (20A per channel)
Signal Input: Standard servo-style connectors
Additional Features: Built-in mixing for differential drive
```

---

## Soldering Procedures

### Required Tools and Materials
- **Soldering Iron:** 25-40W with fine tip
- **Solder:** 60/40 rosin core, 0.6-0.8mm diameter
- **Flux:** Additional rosin flux for clean joints
- **Heat Shrink:** Various sizes (2mm, 4mm, 6mm)
- **Wire Strippers:** For 16-24 AWG wire
- **Multimeter:** For continuity testing

### General Soldering Guidelines

#### Preparation Steps
1. **Clean all surfaces** with isopropyl alcohol
2. **Pre-tin all wires and pads** before joining
3. **Use appropriate wire gauge:**
   - Main power: 16-18 AWG
   - Motor connections: 16-18 AWG
   - Signal wires: 22-24 AWG

#### Soldering Technique
1. **Heat the joint** - not the solder
2. **Feed solder into the joint** - let it flow naturally
3. **Remove solder first**, then iron
4. **Keep joint still** until solder cools
5. **Inspect joint** - should be shiny and cone-shaped

### Specific Connection Procedures

#### XT30 Connector Installation
**Critical Safety Note:** XT30 connectors are polarized. Incorrect installation can damage components.

```
Male Connector (Battery Side):
- Larger terminal: Positive (Red wire)
- Smaller terminal: Negative (Black wire)

Female Connector (Robot Side):
- Larger socket: Positive (Red wire)
- Smaller socket: Negative (Black wire)
```

**Installation Steps:**
1. **Slide heat shrink** over wire before soldering
2. **Strip wire 4-5mm** - just enough to fill terminal cup
3. **Pre-tin stripped wire** with thin solder coating
4. **Heat terminal cup** with soldering iron
5. **Insert wire and add solder** to fill cup completely
6. **Hold steady** until solder cools (3-5 seconds)
7. **Slide heat shrink** over connection and shrink with heat gun
8. **Test with multimeter** for continuity and correct polarity

#### Motor Terminal Connections
**Motor Wire Gauge:** Use 16-18 AWG for adequate current capacity

**Procedure:**
1. **Clean motor terminals** with fine sandpaper if needed
2. **Strip wire 3-4mm** - enough to wrap around terminal
3. **Pre-tin wire and terminal** lightly
4. **Wrap wire around terminal** clockwise (tightening direction)
5. **Solder connection** with adequate heat and solder
6. **Cover with heat shrink** extending beyond bare metal
7. **Test motor direction** before final assembly

#### ESC Power Input Soldering
**Wire Gauge:** 16-18 AWG for main power, 22-24 AWG for signals

**Power Input Steps:**
1. **Identify correct pads** on ESC (usually marked V+ and GND)
2. **Pre-tin ESC pads** with thin layer of solder
3. **Strip and pre-tin wires** - keep length minimal
4. **Solder red wire to V+** pad quickly to avoid overheating
5. **Solder black wire to GND** pad
6. **Strain relief** with cable tie or heat shrink boot

#### Signal Wire Connections
**Important:** Signal wires carry 3.3V or 5V logic levels - use appropriate wire gauge

**ESP32 to ESC Signal Connections:**
1. **Use servo-style connectors** if ESC has them
2. **Solder directly to pads** if no connectors available
3. **Color coding:**
   - Red: 5V power (if needed)
   - Black/Brown: Ground
   - White/Orange: PWM signal
4. **Keep signal wires short** to minimize interference

---

## Wire Management

### Routing Guidelines
- **Separate power and signal wires** by at least 10mm
- **Use shortest practical wire lengths** to reduce weight
- **Secure all connections** with heat shrink or electrical tape
- **Avoid sharp edges** that could cut wires during combat
- **Plan for disassembly** - don't permanently trap wires

### Protection Methods
1. **Heat Shrink Tubing:** Primary protection for all solder joints
2. **Cable Ties:** Strain relief and organization
3. **Split Loom Tubing:** Protection in high-wear areas
4. **3M Dual Lock:** Secure component mounting without permanent attachment

### Weight Optimization
- **Minimize wire length** - every inch adds weight
- **Use appropriate gauge** - don't oversize unnecessarily
- **Remove excess insulation** where safe to do so
- **Bundle related wires** with thin cable ties

---

## Testing and Verification

### Pre-Power Testing
**Always test before applying power!**

#### Continuity Tests
1. **Battery to kill switch:** Verify switch operation
2. **Kill switch to ESC:** Check correct polarity
3. **ESC to motors:** Verify no shorts between channels
4. **Signal connections:** Check ESP32 to ESC signal paths

#### Resistance Tests
1. **Motor resistance:** Should be 1-10 ohms typically
2. **Power path resistance:** Should be near zero
3. **Insulation resistance:** Check for shorts to chassis

### Initial Power-Up Procedure
**Safety First: Always test with robot on blocks!**

1. **Set kill switch to OFF**
2. **Connect battery** - verify no sparks or heating
3. **Check voltage at ESC input** with multimeter
4. **Turn kill switch to ON** - verify voltage passes through
5. **Check 5V output** from ESC if used for ESP32 power
6. **Program and test ESP32** before connecting to motors

### Motor Direction Testing
1. **Connect one motor at a time**
2. **Apply brief forward command** from ESP32
3. **Observe wheel rotation direction**
4. **Swap motor wires if direction is incorrect**
5. **Test both motors** before final assembly

---

## Troubleshooting

### Common Issues and Solutions

#### No Power to System
**Symptoms:** No LED indicators, no motor response
**Check:**
- Battery voltage (should be >11V for 3S)
- Kill switch continuity
- XT30 connector polarity
- Blown fuses or damaged components

#### Motors Not Responding
**Symptoms:** Power present but motors don't move
**Check:**
- ESC programming and calibration
- Signal wire connections
- Motor wire continuity
- ESP32 PWM output signals

#### Wrong Motor Direction
**Symptoms:** Robot moves opposite to commanded direction
**Solutions:**
- Swap motor wires at ESC output
- Modify software channel mapping
- Check PWM signal polarity

#### Intermittent Operation
**Symptoms:** System works sometimes, fails randomly
**Check:**
- Loose solder joints
- Damaged wire insulation
- Poor connections under vibration
- Inadequate strain relief

#### ESC Overheating
**Symptoms:** ESC becomes hot during operation
**Causes:**
- Overcurrent from stalled motors
- Inadequate cooling airflow
- Damaged ESC components
- Excessive ambient temperature

### Diagnostic Tools
1. **Multimeter:** Voltage, current, and resistance measurements
2. **Oscilloscope:** PWM signal analysis (if available)
3. **Current Clamp:** Monitor motor current draw
4. **Battery Tester:** Verify battery health and capacity

### Field Repair Kit
**Essential Items for Competition Day:**
- Spare XT30 connectors
- Pre-tinned wire lengths
- Heat shrink tubing
- Portable soldering iron
- Multimeter
- Spare ESC (if budget allows)
- Electrical tape
- Wire strippers/crimpers

---

## Safety Considerations

### Electrical Safety
- **Never work on live circuits** - always disconnect battery
- **Verify kill switch operation** before each use
- **Use proper fusing** to protect against overcurrent
- **Insulate all connections** to prevent shorts
- **Keep spare batteries** in proper storage containers

### LiPo Battery Safety
- **Charge only with balance charger** (ISDT PD60 recommended)
- **Never charge unattended** - monitor temperature and voltage
- **Store at 3.8V per cell** for long-term storage
- **Use fireproof charging bags** for safety
- **Dispose of damaged batteries** at proper recycling centers

### Competition Safety
- **Remove weapon safety link** only when authorized
- **Test all safety systems** before each match
- **Have emergency procedures** clearly planned
- **Carry proper documentation** of wiring and safety systems

---

## Revision History

| Version | Date | Changes |
|---|---|---|
| 1.0 | 2025-07-08 | Initial creation of wiring guide |
| | | Added comprehensive soldering procedures |
| | | Included both ESC options (Repeat and Weka) |
| | | Added troubleshooting section |

---

**Remember:** When in doubt about any electrical connection, stop and verify before proceeding. A careful build now prevents failures during competition!

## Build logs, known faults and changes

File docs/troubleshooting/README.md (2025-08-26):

# Troubleshooting Guide

This folder is for common issues and solutions. Add troubleshooting documentation here.

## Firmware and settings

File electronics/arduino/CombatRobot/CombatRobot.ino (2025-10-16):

// ============================================================================
// Combat Robot Controller - SPARC Compliant
// ============================================================================
// Beginner-friendly ESP32-based controller for combat robots with weapon support
// Features: Drive control, weapon systems, Bluetooth pairing, safety features
// ============================================================================

#include <Bluepad32.h>
#include <ESP32Servo.h>
#include <uni.h>
#include "CombatWeapon.h"  // Our weapon library

// ============================================================================
// WEAPON SELECTION - Choose ONE weapon type!
// ============================================================================
// Uncomment ONE of these lines to select your weapon:

//#define USE_VERTICAL_SPINNER
//#define USE_HORIZONTAL_SPINNER
//#define USE_LIFTER
//#define USE_FLIPPER
#define USE_NO_WEAPON  // Default - safe for testing

// ============================================================================
// CONFIGURATION
// ============================================================================

// SPARC Pairing Mode
const bool PAIRING_MODE = false;  // Set to true to pair new controllers

// Pin assignments
const int LEFT_MOTOR_PIN = D9;
const int RIGHT_MOTOR_PIN = D10;
const int WEAPON_PIN = D8;

// Motor direction adjustment
const bool INVERT_LEFT_MOTOR = true;
const bool INVERT_RIGHT_MOTOR = true;
const bool INVERT_TURN_DIRECTION = (INVERT_LEFT_MOTOR && INVERT_RIGHT_MOTOR);

// Control sensitivity
const int JOYSTICK_DEAD_ZONE = 102;
const int TRIGGER_THRESHOLD = 10;
const unsigned long TURN_BURST_DURATION = 250;  // milliseconds

// Timing constants
const unsigned long UPDATE_INTERVAL = 50;     // milliseconds
const unsigned long COMMAND_TIMEOUT = 1000;   // milliseconds

// ESC settings
const int ESC_CAL_DELAY = 2000;    // milliseconds
const int STARTUP_DELAY = 3000;    // milliseconds
const bool VERBOSE_DEBUG = true;

// ESC speed constants
const int NEUTRAL_SPEED = 1500;    // microseconds
const int MIN_SPEED = 1000;        // microseconds
const int MAX_SPEED = 2000;        // microseconds

// ============================================================================
// WEAPON INSTANTIATION - Automatic based on #define
// ============================================================================

#if defined(USE_VERTICAL_SPINNER)
    SpinnerWeapon weapon(WEAPON_VERTICAL_SPINNER);
    #define WEAPON_NAME "Vertical Spinner"
#elif defined(USE_HORIZONTAL_SPINNER)
    SpinnerWeapon weapon(WEAPON_HORIZONTAL_SPINNER);
    #define WEAPON_NAME "Horizontal Spinner"
#elif defined(USE_LIFTER)
    LifterWeapon weapon;
    #define WEAPON_NAME "Lifter"
#elif defined(USE_FLIPPER)
    FlipperWeapon weapon;
    #define WEAPON_NAME "Flipper"
#else
    NoWeapon weapon;
    #define WEAPON_NAME "None"
#endif

// ============================================================================
// CONTROL STATES
// ============================================================================

enum ControlState {
    STATE_STOPPED,
    STATE_JOYSTICK,
    STATE_TRIGGER,
    STATE_BUMPER_TURNING
};

// ============================================================================
// GLOBAL VARIABLES
// ============================================================================

// Controller management
ControllerPtr myControllers[BP32_MAX_GAMEPADS];
bool controllerConnected = false;

// Drive motors
Servo leftESC;
Servo rightESC;
int leftSpeed = NEUTRAL_SPEED;
int rightSpeed = NEUTRAL_SPEED;
bool escsArmed = false;

// State management
ControlState currentState = STATE_STOPPED;
unsigned long turnStartTime = 0;
bool turnBurstActive = false;
unsigned long lastCommandTime = 0;
unsigned long lastUpdate = 0;

// ============================================================================
// WEAPON CONFIGURATION
// ============================================================================

void configureWeapon() {
    Serial.print("Weapon type: ");
    Serial.println(WEAPON_NAME);
    
    #if defined(USE_VERTICAL_SPINNER) || defined(USE_HORIZONTAL_SPINNER)
        weapon.setControlMode(2);           // Variable speed (right stick)
        weapon.setSpinUpTime(2000);         // 2 seconds to full speed
        weapon.setSpinDownTime(3000);       // 3 seconds to stop
        weapon.setMaxSpeed(2000);           // Full power
        weapon.setSafetyDelay(3000);        // 3 second safety delay
        weapon.setRumbleFeedback(true);     // Enable rumble feedback
        
        Serial.println("  Control: Right stick Y-axis (push up = faster)");
        Serial.println("  Rumble: Enabled (intensity matches speed)");
        Serial.println("  Safety: 3-second delay after connection");
        
    #elif defined(USE_LIFTER)
        weapon.setUpButton(1);              // R1 = up
        weapon.setDownButton(0);            // R2 = down
        weapon.setControlMode(0);           // Button mode
        weapon.setRange(0, 90);             // 0-90 degrees
        weapon.setSpeed(120);               // 120 degrees/second
        weapon.setSafetyDelay(3000);        // 3 second safety delay
        
        Serial.println("  Control: R1 = Up, R2 = Down");
        Serial.println("  Range: 0-90 degrees");
        
    #elif defined(USE_FLIPPER)
        weapon.setEnableButton(0);          // R2
        weapon.setControlMode(0);           // Tap mode
        weapon.setFireDuration(150);        // 150ms pulse
        weapon.setCooldownTime(1000);       // 1 second cooldown
        weapon.setSafetyDelay(3000);        // 3 second safety delay
        
        Serial.println("  Control: R2 = Fire");
        Serial.println("  Duration: 150ms pulse");
    #else
        Serial.println("  No weapon configured");
    #endif
}

// ============================================================================
// ESC INITIALIZATION
// ============================================================================

void armESCs() {
    Serial.println("\n=== Starting ESC Arming Sequence ===");
    
    // Attach and initialize drive ESCs
    leftESC.attach(LEFT_MOTOR_PIN, MIN_SPEED, MAX_SPEED);
    rightESC.attach(RIGHT_MOTOR_PIN, MIN_SPEED, MAX_SPEED);
    
    Serial.println("Waiting for ESC power-up...");
    delay(STARTUP_DELAY);

    Serial.println("Setting neutral position for arming...");
    leftESC.writeMicroseconds(NEUTRAL_SPEED);
    rightESC.writeMicroseconds(NEUTRAL_SPEED);
    delay(ESC_CAL_DELAY);
    
    escsArmed = true;
    Serial.println("=== Drive ESCs Armed! ===\n");
    
    // Initialize weapon system
    Serial.println("=== Initializing Weapon System ===");
    weapon.begin(WEAPON_PIN);
    configureWeapon();
    Serial.println("=== Weapon System Ready! ===\n");
}

// ============================================================================
// HELPER FUNCTIONS
// ============================================================================

int applyDeadZone(int value, int deadZone) {
    return (abs(value) < deadZone) ? 0 : value;
}

int invertSpeed(int speed) {
    return MIN_SPEED + (MAX_SPEED - speed);
}

void stopMotors() {
    leftSpeed = NEUTRAL_SPEED;
    rightSpeed = NEUTRAL_SPEED;
    currentState = STATE_STOPPED;
    
    if (VERBOSE_DEBUG) {
        Serial.println("Motors STOPPED");
    }
}

// ============================================================================
// DRIVE CONTROL HANDLERS
// ============================================================================

void handleJoystickControl(ControllerPtr ctl) {
    int axisX = applyDeadZone(ctl->axisX(), JOYSTICK_DEAD_ZONE);
    int axisY = applyDeadZone(ctl->axisY(), JOYSTICK_DEAD_ZONE);
    
    if (INVERT_TURN_DIRECTION) {
        axisX = -axisX;
    }
    
    // Mix for differential drive
    int leftMotorInput = constrain(axisY + (axisX / 2), -512, 512);
    int rightMotorInput = constrain(axisY - (axisX / 2), -512, 512);
    
    // Map to ESC range
    leftSpeed = map(leftMotorInput, -512, 512, MIN_SPEED, MAX_SPEED);
    rightSpeed = map(rightMotorInput, -512, 512, MIN_SPEED, MAX_SPEED);
    
    // Apply motor direction inversion
    if (INVERT_LEFT_MOTOR) leftSpeed = invertSpeed(leftSpeed);
    if (INVERT_RIGHT_MOTOR) rightSpeed = invertSpeed(rightSpeed);
    
    currentState = STATE_JOYSTICK;
    
    if (VERBOSE_DEBUG) {
        Serial.printf("JOYSTICK - Left: %d, Right: %d\n", leftSpeed, rightSpeed);
    }
}

void handleTriggerControl(ControllerPtr ctl) {
    int leftTrigger = ctl->throttle();
    int rightTrigger = ctl->brake();
    
    bool leftPressed = (leftTrigger > TRIGGER_THRESHOLD);
    bool rightPressed = (rightTrigger > TRIGGER_THRESHOLD);
    
    // Both triggers = emergency stop
    if (leftPressed && rightPressed) {
        leftSpeed = NEUTRAL_SPEED;
        rightSpeed = NEUTRAL_SPEED;
        weapon.emergencyStop();
        
        if (VERBOSE_DEBUG) {
            Serial.println("TRIGGER - EMERGENCY STOP");
        }
        return;
    }
    
    // Right trigger = forward boost
    if (rightPressed) {
        leftSpeed = map(rightTrigger, 0, 1023, NEUTRAL_SPEED, MAX_SPEED);
        rightSpeed = leftSpeed;
        
        if (INVERT_LEFT_MOTOR) leftSpeed = invertSpeed(leftSpeed);
        if (INVERT_RIGHT_MOTOR) rightSpeed = invertSpeed(rightSpeed);
        
        if (VERBOSE_DEBUG) {
            Serial.printf("TRIGGER - Forward boost: %d\n", leftSpeed);
        }
    }
    // Left trigger = reverse retreat
    else if (leftPressed) {
        leftSpeed = map(leftTrigger, 0, 1023, NEUTRAL_SPEED, MIN_SPEED);
        rightSpeed = leftSpeed;
        
        if (INVERT_LEFT_MOTOR) leftSpeed = invertSpeed(leftSpeed);
        if (INVERT_RIGHT_MOTOR) rightSpeed = invertSpeed(rightSpeed);
        
        if (VERBOSE_DEBUG) {
            Serial.printf("TRIGGER - Reverse retreat: %d\n", leftSpeed);
        }
    }
    
    currentState = STATE_TRIGGER;
}

void handleBumperControl(ControllerPtr ctl) {
    bool leftBumper = ctl->l1();
    bool rightBumper = ctl->r1();
    
    // Swap if turn direction is inverted
    if (INVERT_TURN_DIRECTION) {
        bool temp = leftBumper;
        leftBumper = rightBumper;
        rightBumper = temp;
    }
    
    // Start turn burst on button press
    if ((leftBumper || rightBumper) && currentState != STATE_BUMPER_TURNING) {
        turnStartTime = millis();
        turnBurstActive = true;
        currentState = STATE_BUMPER_TURNING;
        
        if (VERBOSE_DEBUG) {
            Serial.printf("BUMPER - Starting %s turn\n", leftBumper ? "LEFT" : "RIGHT");
        }
    }
    
    // Execute turn
    if (leftBumper) {
        leftSpeed = MIN_SPEED;
        rightSpeed = MAX_SPEED;
    } else if (rightBumper) {
        leftSpeed = MAX_SPEED;
        rightSpeed = MIN_SPEED;
    }
    
    // Apply motor direction inversion
    if (INVERT_LEFT_MOTOR) leftSpeed = invertSpeed(leftSpeed);
    if (INVERT_RIGHT_MOTOR) rightSpeed = invertSpeed(rightSpeed);
}

// ============================================================================
// MAIN CONTROL LOGIC
// ============================================================================

void processGamepad(ControllerPtr ctl) {
    if (!escsArmed) return;
    
    lastCommandTime = millis();
    
    // Update weapon (happens every loop)
    weapon.update(ctl);
    
    // Get controller inputs
    bool leftBumper = ctl->l1();
    bool rightBumper = ctl->r1();
    int leftTrigger = ctl->throttle();
    int rightTrigger = ctl->brake();
    int axisX = ctl->axisX();
    int axisY = ctl->axisY();
    
    // Priority: Bumpers > Triggers > Joystick
    if (leftBumper || rightBumper) {
        handleBumperControl(ctl);
    }
    else if (leftTrigger > TRIGGER_THRESHOLD || rightTrigger > TRIGGER_THRESHOLD) {
        handleTriggerControl(ctl);
        turnBurstActive = false;
    }
    else if (abs(axisX) > JOYSTICK_DEAD_ZONE || abs(axisY) > JOYSTICK_DEAD_ZONE) {
        handleJoystickControl(ctl);
        turnBurstActive = false;
    }
    else {
        // No input - check for turn burst timeout
        if (turnBurstActive && (millis() - turnStartTime >= TURN_BURST_DURATION)) {
            turnBurstActive = false;
            stopMotors();
            
            if (VERBOSE_DEBUG) {
                Serial.println("BUMPER - Turn burst complete, STOPPED");
            }
        }
        else if (!turnBurstActive && currentState != STATE_STOPPED) {
            stopMotors();
        }
    }
}

void processControllers() {
    bool hasActiveController = false;
    
    // Find first active controller
    for (auto myController : myControllers) {
        if (myController && myController->isConnected() && myController->hasData()) {
            processGamepad(myController);
            hasActiveController = true;
            break;  // Only use one controller at a time
        }
    }
    
    // Safety: stop everything if no active controller
    if (!hasActiveController) {
        stopMotors();
        weapon.emergencyStop();
    }
}

void updateMotors() {
    if (!escsArmed) return;
    
    leftESC.writeMicroseconds(leftSpeed);
    rightESC.writeMicroseconds(rightSpeed);
}

// ============================================================================
// BLUEPAD32 CALLBACKS
// ============================================================================

void onConnectedController(ControllerPtr ctl) {
    bool foundEmptySlot = false;
    
    for (int i = 0; i < BP32_MAX_GAMEPADS; i++) {
        if (myControllers[i] == nullptr) {
            ControllerProperties properties = ctl->getProperties();
            
            Serial.printf("Controller attempting connection: %02x:%02x:%02x:%02x:%02x:%02x\n",
                properties.btaddr[0], properties.btaddr[1], properties.btaddr[2],
                properties.btaddr[3], properties.btaddr[4], properties.btaddr[5]);
            
            // Handle pairing mode
            if (PAIRING_MODE) {
                bd_addr_t controller_addr;
                memcpy(controller_addr, properties.btaddr, 6);
                uni_bt_allowlist_add_addr(controller_addr);
                uni_bt_allowlist_set_enabled(true);
                
                Serial.println("\n*** CONTROLLER SUCCESSFULLY PAIRED! ***");
                Serial.println("*** Set PAIRING_MODE to false and re-upload ***\n");
            }
            
            myControllers[i] = ctl;
            controllerConnected = true;
            foundEmptySlot = true;
            
            // Tell weapon about connection time (for safety delay)
            weapon.setConnectionTime(millis());
            
            Serial.printf("Controller connected at index %d\n", i);
            break;
        }
    }
    
    if (!foundEmptySlot) {
        Serial.println("SAFETY: Controller connection rejected - no available slots");
        ctl->disconnect();
    }
}

void onDisconnectedController(ControllerPtr ctl) {
    for (int i = 0; i < BP32_MAX_GAMEPADS; i++) {
        if (myControllers[i] == ctl) {
            myControllers[i] = nullptr;
            controllerConnected = false;
            
            // Emergency stop on disconnect
            stopMotors();
            weapon.emergencyStop();
            
            Serial.printf("Controller disconnected from index %d\n", i);
            break;
        }
    }
}

// ============================================================================
// SETUP
// ============================================================================

void setup() {
    Serial.begin(115200);
    Serial.println("\n=== Combat Robot Controller - SPARC COMPLIANT ===");
    Serial.println("Initializing...\n");
    
    // Allocate PWM timers
    ESP32PWM::allocateTimer(0);
    ESP32PWM::allocateTimer(1);
    ESP32PWM::allocateTimer(2);
    ESP32PWM::allocateTimer(3);
    
    // Set servo frequency
    leftESC.setPeriodHertz(50);
    rightESC.setPeriodHertz(50);
    
    // Initialize Bluepad32
    BP32.setup(&onConnectedController, &onDisconnectedController);
    
    // SPARC Compliance Setup
    Serial.println("=== SPARC Radio Control Compliance ===");
    
    if (!PAIRING_MODE) {
        uni_bt_allowlist_set_enabled(true);
        Serial.println("SECURITY: Controller allowlist ENABLED");
        
        // Display paired controllers
        const bd_addr_t* addresses;
        int total;
        uni_bt_allowlist_get_all(&addresses, &total);
        
        if (total > 0) {
            Serial.printf("\nPaired controllers (%d):\n", total);
            for (int i = 0; i < total; i++) {
                Serial.printf("  %d. %02x:%02x:%02x:%02x:%02x:%02x\n", i + 1,
                    addresses[i][0], addresses[i][1], addresses[i][2],
                    addresses[i][3], addresses[i][4], addresses[i][5]);
            }
        } else {
            Serial.println("\n*** WARNING: NO CONTROLLERS PAIRED! ***");
            Serial.println("Set PAIRING_MODE = true to pair a controller\n");
        }
        
    } else {
        uni_bt_allowlist_set_enabled(false);
        Serial.println("\n*** PAIRING MODE ACTIVE ***");
        Serial.println("Turn on your controller to pair it\n");
    }
    
    Serial.println("SPARC Failsafe: Active (SPARC 6.4.1)");
    Serial.println("Radio System: 2.4GHz Bluetooth (SPARC 6.1)\n");
    
    // Arm ESCs and initialize weapon
    armESCs();
    
    Serial.println("=== Setup Complete! ===");
    Serial.println("Waiting for controller connection...\n");
}

// ============================================================================
// MAIN LOOP
// ============================================================================

void loop() {
    unsigned long currentMillis = millis();
    
    // Update Bluepad32 and process controllers
    if (BP32.update()) {
        processControllers();
    }
    
    // SPARC Failsafe - stop if no command received
    if (controllerConnected && (currentMillis - lastCommandTime > COMMAND_TIMEOUT)) {
        if (currentState != STATE_STOPPED) {
            Serial.println("SPARC FAILSAFE: Signal lost - stopping all motors");
            stopMotors();
            weapon.emergencyStop();
        }
    }
    
    // Update motors at fixed interval
    if (currentMillis - lastUpdate >= UPDATE_INTERVAL) {
        lastUpdate = currentMillis;
        updateMotors();
    }
    
    // Small delay for task scheduling
    vTaskDelay(1);
}

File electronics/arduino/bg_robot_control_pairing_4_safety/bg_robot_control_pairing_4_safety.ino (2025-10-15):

#include <Bluepad32.h>
#include <ESP32Servo.h>
#include <uni.h>  // Required for SPARC-compliant controller pairing

// ============================================================================
// CONFIGURATION - Adjust these for your robot
// ============================================================================

// ============================================================================
// SPARC COMPLIANCE - CONTROLLER PAIRING (IMPORTANT!)
// ============================================================================
// 
// SPARC rules require that robots have a way to prevent radio conflicts.
// This pairing system ensures ONLY YOUR controller can connect to your robot.
// 
// HOW TO PAIR YOUR CONTROLLER (do this ONCE before competition):
// 1. Set PAIRING_MODE to true
// 2. Upload the code to your robot
// 3. Turn on your robot and controller
// 4. The controller will connect and be saved to the robot's memory
// 5. Set PAIRING_MODE back to false
// 6. Re-upload the code
// 
// Your controller is now permanently paired! Even after power cycling,
// only your controller can connect. This prevents other competitors from
// accidentally taking control of your robot.
// 
// PAIRING MODE: Set to true ONLY when pairing a new controller
//               Set to false for competition and normal use
const bool PAIRING_MODE = false;  // CHANGE THIS TO true TO PAIR, false FOR COMPETITION
//
// ============================================================================

// Motor pins
const int LEFT_MOTOR_PIN = D9;
const int RIGHT_MOTOR_PIN = D10;

// Motor direction adjustment (flip these if motors spin wrong way)
const bool INVERT_LEFT_MOTOR = true;
const bool INVERT_RIGHT_MOTOR = true;

// Automatic turn compensation - don't change this!
// When BOTH motors are inverted, the turning differential gets reversed.
// This flag automatically compensates by swapping turn directions in the code.
const bool INVERT_TURN_DIRECTION = (INVERT_LEFT_MOTOR && INVERT_RIGHT_MOTOR);

// Control sensitivity
const int JOYSTICK_DEAD_ZONE = 102;  // 20% dead zone (out of 512 max)
const int TRIGGER_THRESHOLD = 10;     // Minimal threshold to prevent accidental bumps

// Turn settings
const unsigned long TURN_BURST_DURATION = 250;  // Bumper tap = 250ms turn

// Timing
const unsigned long UPDATE_INTERVAL = 50;      // Motor update rate (20Hz)
const unsigned long COMMAND_TIMEOUT = 1000;    // Safety timeout if no input (SPARC 6.4.1)

// ESC calibration settings
const int ESC_CAL_DELAY = 2000;
const int STARTUP_DELAY = 3000;

// Debug output (set to false to reduce serial spam)
const bool VERBOSE_DEBUG = true;

// ============================================================================
// ESC CONSTANTS - Standard PWM values for ESCs (don't change unless you know why)
// ============================================================================

const int NEUTRAL_SPEED = 1500;  // ESC stopped position
const int MIN_SPEED = 1000;      // Full reverse
const int MAX_SPEED = 2000;      // Full forward

// ============================================================================
// CONTROL STATES - Robot can only be in one state at a time
// ============================================================================

enum ControlState {
    STATE_STOPPED,          // No input or safety stop
    STATE_JOYSTICK,         // Precision control with left stick
    STATE_TRIGGER,          // Fast movement with triggers
    STATE_BUMPER_TURNING    // Quick aim adjustment with bumpers
};

// ============================================================================
// GLOBAL VARIABLES
// ============================================================================

// Bluepad32 controller management
ControllerPtr myControllers[BP32_MAX_GAMEPADS];
bool controllerConnected = false;

// Motor control
Servo leftESC;
Servo rightESC;
int leftSpeed = NEUTRAL_SPEED;
int rightSpeed = NEUTRAL_SPEED;
bool escsArmed = false;

// State management
ControlState currentState = STATE_STOPPED;
unsigned long turnStartTime = 0;
bool turnBurstActive = false;  // True during 250ms tap turn
unsigned long lastCommandTime = 0;
unsigned long lastUpdate = 0;

// ============================================================================
// ESC INITIALIZATION
// ============================================================================

void armESCs() {
    Serial.println("=== Starting ESC Arming Sequence ===");
    
    // Attach ESCs to pins
    leftESC.attach(LEFT_MOTOR_PIN, MIN_SPEED, MAX_SPEED);
    rightESC.attach(RIGHT_MOTOR_PIN, MIN_SPEED, MAX_SPEED);
    
    // Wait for ESC power-up
    Serial.println("Waiting for ESC power-up...");
    delay(STARTUP_DELAY);

    // Set neutral position for arming
    Serial.println("Setting neutral position for arming...");
    leftESC.writeMicroseconds(NEUTRAL_SPEED);
    rightESC.writeMicroseconds(NEUTRAL_SPEED);
    delay(ESC_CAL_DELAY);
    
    escsArmed = true;
    Serial.println("=== ESCs Armed and Ready! ===\n");
}

// ============================================================================
// HELPER FUNCTIONS
// ============================================================================

// Apply dead zone to joystick input
int applyDeadZone(int value, int deadZone) {
    return (abs(value) < deadZone) ? 0 : value;
}

// Invert motor direction around neutral point
// IMPORTANT: This is applied in each control handler, not at the end.
// This preserves the motor differential needed for proper turning.
int invertSpeed(int speed) {
    return MIN_SPEED + (MAX_SPEED - speed);
}

// Stop all motors
void stopMotors() {
    leftSpeed = NEUTRAL_SPEED;
    rightSpeed = NEUTRAL_SPEED;
    currentState = STATE_STOPPED;
    
    if (VERBOSE_DEBUG) {
        Serial.println("Motors STOPPED");
    }
}

// ============================================================================
// CONTROL MODE HANDLERS
// ============================================================================
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

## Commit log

2025-06-16 file reorg
    [CastHubsSetCores.3mf, FoamHexCore_3mm_shaft.3mf, FoamHexCore_deadshaft.3mf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]
2025-07-05 Kill switch hex mount
    [hexHolderkillSwitch_Component v1.step]
2025-10-15 Refactor motor control and configuration settings
    Refactor and reorganize configuration constants, control states, and motor control logic for improved clarity and functionality.
2025-10-15 Add SPARC-compliant controller pairing for robot
    This code implements a SPARC-compliant controller pairing system for a combat robot, ensuring only authorized controllers can connect. It includes motor control logic, joystick handling, and safety f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

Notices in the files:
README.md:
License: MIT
